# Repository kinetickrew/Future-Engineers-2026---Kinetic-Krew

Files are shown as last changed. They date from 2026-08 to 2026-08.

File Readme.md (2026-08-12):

# WRO 2026 Future Engineers — Engineering Documentation

## Table of Contents

1. [Competition Context](#competition-context)
2. [On The Name](#On-The-Name)
3. [System Architecture Overview](#system-architecture-overview)
4. [Chassis and Construction Materials](#chassis-and-construction-materials)
5. [Bill of Materials](#Bill-of-Materials)
6. [Robot at a Glance](#robot-at-a-glance)
7. [Layered Chassis Design](#layered-chassis-design)
8. [Design Evolution](Design-Evolution)
9. [Steering Mechanism — Ackermann Steering](#steering-mechanism--ackermann-steering)
10. [Servo Motor Integration with the Ackermann Steering Mechanism](#servo-motor-integration-with-the-ackermann-steering-mechanism)
11. [Differential Gear System](#differential-gear-system)
12. [Relation with the DC Motor](#relation-with-the-dc-motor)
13. [Power System](Power-System)
14. [Motor Torque & Top Speed: Theoretical vs. Measured](#motor-torque--top-speed-theoretical-vs-measured)
15. [Software Architecture](Software-Architecture)
16. [Getting Started](Getting-Started)
17. [Engineering Decisions](#Engineering-Decisions)
18. [Computer Vision Pipeline & Mathematical Foundations](#computer-vision-pipeline--mathematical-foundations)
19. [ESP32 Maze-Navigating & Self-Stabilizing Subsystem](#esp32-maze-navigating--self-stabilizing-subsystem)
20. [PID Control — Background Theory](#pid-control--background-theory)
21. [Glossary](#glossary)

---

## Competition Context

WRO Future Engineers is the World Robot Olympiad's self-driving car category, aimed at students roughly 14–19 years old. Teams design, build, and program a model vehicle that must complete laps of a track fully autonomously, without any remote control, using whatever combination of controllers, motors, and sensors they choose as long as it fits the general rules. Students design a model car, equip it with electromechanical components, and program it to autonomously drive on a track and avoid obstacles. The category is explicitly built to mirror real self-driving car research, so teams are encouraged to reason about the same engineering trade-offs that full-size autonomous vehicle manufacturers face: steering geometry, sensor fusion, control-loop tuning, and mechanical reliability under repeated real-world testing.

The 2026 season runs two distinct challenge formats, each scored as a timed, single-car run rather than a head-to-head race:

- **Open Challenge** — the vehicle must complete three laps on the track with random placements of the inside track walls, testing pure lane-keeping and heading control without obstacles.
- **Obstacle Challenge** — the vehicle must complete three laps on the track with randomly placed green and red traffic signs, where the signs indicate which side of the lane the vehicle must follow: a red pillar means "keep to the right of the lane" and a green pillar means "keep to the left." Later rounds of the obstacle challenge also require the vehicle to identify a parking space and execute a parallel-parking maneuver to finish the run.

Both challenges are run as **Time Attack** events — only one car is on the track at a time, and each car tries to record the best time driving several fully autonomous laps. Teams are also evaluated on an **Engineering Journal**, which documents design decisions, prototyping iterations, and justifications for chosen components — this repository and its documentation serve that purpose for our team.

Because obstacle placement, wall layout, and (in later rounds) parking-bay location are randomized before each run, the robot cannot rely on a memorized path. This is the core reason our design combines deterministic mechanical geometry (Ackermann steering, a differential drivetrain) with adaptive, sensor-driven control loops (computer vision pillar detection, LiDAR wall-following, IMU heading correction) rather than depending on either alone.

---

## On The Name

We named our robot **Steve**. Not an acronym, not a backronym, not "Self-Tracking Vehicle with Enhanced-something" — just Steve. Somewhere in our design process, between tuning a discrete Kalman filter, wiring a 3-way LiDAR array, and debugging heading drift across a 0°↔360° boundary, we realized the robot deserved a name with the same energy as the engineering was clearly lacking. We wanted something the judges would remember. Turns out nothing is more memorable than a $400 autonomous vehicle named after someone's uncle. So Steve it is — and frankly, given how confidently he snaps to cardinal headings and swerves around pillars, he's earned it

---

## System Architecture Overview

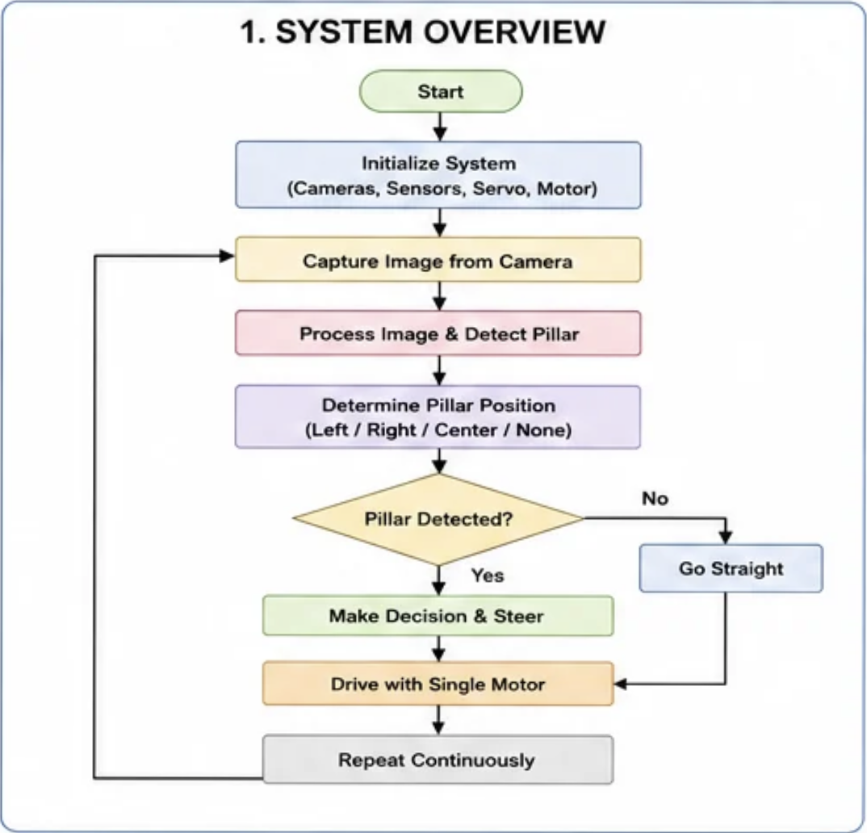
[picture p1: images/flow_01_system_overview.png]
<p align="center"> <br> <em>High-level operating loop: from sensor initialization through continuous drive decisions, tying together the three architecture layers described above.</em> </p>

Our platform is best understood as three cooperating layers:

1. **Mechanical layer** — a LEGO EV3 Technic chassis with Ackermann front steering, a rear differential, and custom 3D-printed sensor/actuator mounts. This layer guarantees that whatever heading and speed commands the software issues get translated into smooth, low-slip motion.
2. **Perception layer** — a camera-based YOLO object detector (ONNX Runtime, CPU inference on the Raspberry Pi 5) for identifying red/green pillars, paired with a 3-way TF-Luna LiDAR array and a BNO055 absolute orientation sensor for wall-following, turn-triggering, and heading stabilization.
3. **Control layer** — a temporal-vote confirmation scheme for stable detections, a one-time waypoint/arc geometry calculation for routing around confirmed obstacles, a PID heading-hold controller for straight-line driving, and a UART/serial link that turns high-level decisions (`CLEAR`, `STOP`, `WAYPOINT`, `REVERSE`) into low-level servo and motor commands.

The sections below document each layer in the depth captured in our design notes, plus supporting engineering background.

---

## Chassis and Construction Materials

Our WRO 2026 Future Engineers robot is built using a combination of LEGO EV3 Technic components and custom-designed 3D-printed parts. This hybrid approach allows us to take advantage of the strength and precision of EV3 while incorporating custom mounts for electronic components that cannot be accommodated using standard LEGO parts.

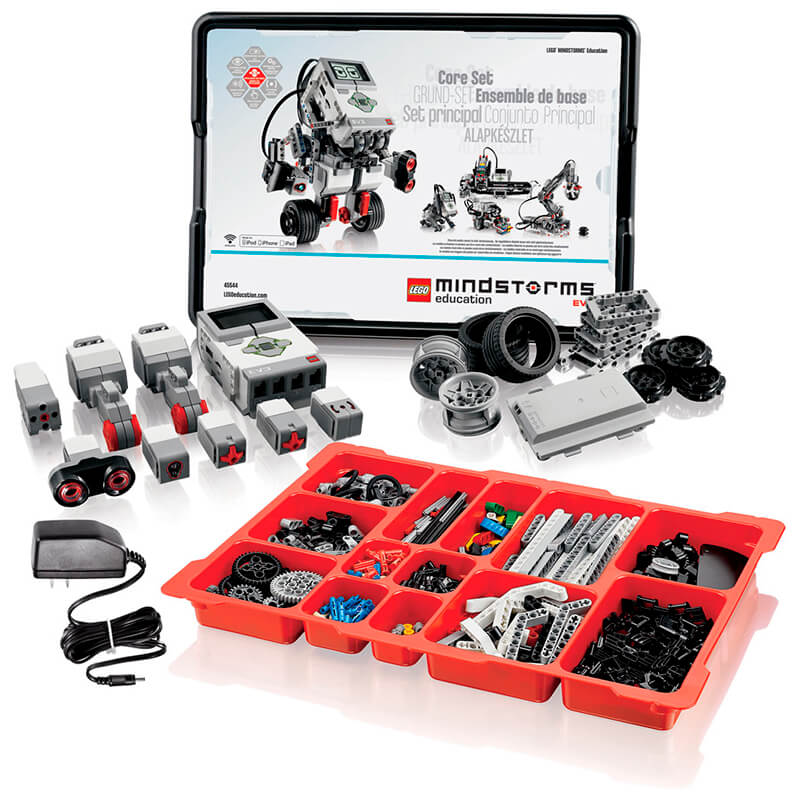
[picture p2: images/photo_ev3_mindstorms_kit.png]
<p align="center"> <br> <em>The LEGO Mindstorms EV3 Core Set — the base kit our Technic chassis, beams, and gearing are built from.</em> </p>

The main chassis is constructed from LEGO EV3 Technic beams, frames, gears, and connectors. These components are specifically designed for mechanical applications and provide excellent structural rigidity while remaining lightweight. Their standardized dimensions ensure accurate alignment of axles, gears, and bearings, resulting in smooth power transmission and reliable mechanical performance. Additionally, the modular nature of the EV3 system allows the robot to be assembled, modified, and repaired quickly, which proved especially valuable during testing and iterative design improvements.

Compared to a fully 3D-printed chassis, the EV3 structure offers several advantages. Although 3D printing provides greater design freedom, large printed frames are generally more susceptible to layer separation, slight dimensional inaccuracies, and deformation under continuous mechanical loads. These issues can affect gear alignment and steering accuracy over time. In contrast, EV3 components are manufactured with high precision and consistent tolerances, ensuring stronger connections, improved durability, and smoother operation of moving mechanical parts. Their proven reliability makes them particularly suitable for a competition robot that must perform consistently over multiple runs.

While EV3 forms the foundation of our robot, several custom 3D-printed components were designed to integrate modern sensors and actuators that cannot be mounted efficiently using LEGO elements alone. These custom parts include:

- **LiDAR mount** — positions the sensor securely and provides an unobstructed 360° field of view for environmental scanning.
- **Camera mount** — placed at an optimized height and angle to maximize the accuracy of lane detection, obstacle recognition, and computer vision algorithms.
- **DC motor mount** — provides a rigid connection between the motor and drivetrain to minimize unwanted movement and improve power transmission efficiency.
- **Servo motor mount** — plays a critical role in the Ackermann steering system by maintaining precise alignment between the servo horn and steering linkage. A rigid and accurately positioned mount ensures consistent steering angles and reduces mechanical play, directly improving the robot's steering precision.

By combining the mechanical reliability of the LEGO EV3 platform with the flexibility of custom 3D-printed components, our robot benefits from both standardized engineering and application-specific customization. This hybrid design improves structural strength, simplifies maintenance, and enables seamless integration of advanced sensors and actuators, resulting in a robust and competition-ready autonomous vehicle.

---

## Bill of Materials

### Mechanical / LEGO Technic Components

Generated from our Stud.io CAD model export — 151 total pieces, ~214g.

| Part # | Part Name | Color | Qty | Weight (g, ea) | Source  | Cost (per pc) | Cost (total) |
| --- | --- | ---: | ---: | ---: | --- | ---: | ---: |
| 62821b | Technic Gear Differential 28T Bevel, Closed Center | Dark Bluish Gray | 1 | — | EV3 Kit | $2.50 | $2.50 |
| 6589 | Technic Gear 12 Tooth Bevel | Tan | 3 | 0.29 | EV3 Kit | $0.35 | $1.05 |
| 41897 | Tire 56 x 28 ZR Street | Black | 2 | 13.98 | EV3 Kit | $0.70 | $1.40 |
| 89201 | Tire 24 x 14 Shallow Tread | Black | 2 | 2.55 | EV3 Kit | $0.30 | $0.60 |
| 56908 | Rim 43.2mm D. x 26mm Technic Racing Small | Gray | 2 | 9.0 | EV3 Kit | $0.60 | $1.20 |
| 55982 | Rim 18mm D. x 14mm w/ Axle Hole | Gray | 2 | 1.75 | EV3 Kit | $0.25 | $0.50 |
| 64179 | Technic Liftarm Frame Thick 5x7 Open Center | Light Bluish Gray | 3 | 5.3 | EV3 Kit | $0.60 | $1.80 |
| 64782 | Technic Panel Plate 5 x 11 x 1 | Orange | 4 | 8.8 | EV3 Kit | $0.80 | $3.20 |
| 41239 | Technic Liftarm Thick 1x13 | Light Bluish Gray | 7 | 3.3 | EV3 Kit | $0.40 | $2.80 |
| 32525 | Technic Liftarm Thick 1x11 | Light Bluish Gray | 6 | 2.8 | EV3 Kit | $0.35 | $2.10 |
| 32524 | Technic Liftarm Thick 1x7 | Light Bluish Gray | 6 | 1.74 | EV3 Kit | $0.25 | $1.50 |
| 40490 | Technic Liftarm Thick 1x9 | Light Bluish Gray | 4 | 2.59 | EV3 Kit | $0.30 | $1.20 |
| 60484 | Technic Liftarm Modified T-Shape Thick 3x3 | Black | 5 | 1.19 | EV3 Kit | $0.25 | $1.25 |
| 32526 | Technic Liftarm Modified Bent L-Shape 3x5 | White / Lt Bluish Gray | 2 + 4 | 1.77 | EV3 Kit | $0.30 | $1.80 |
| 32140 | Technic Liftarm Modified Bent L-Shape 2x4 | Light Bluish Gray | 2 | 1.43 | EV3 Kit | $0.25 | $0.50 |
| 32316 | Technic Liftarm Thick 1x5 | Light Bluish Gray | 2 | 1.21 | EV3 Kit | $0.20 | $0.40 |
| 43857 | Technic Liftarm Thick 1x2 | Light Bluish Gray | 4 | 0.4 | EV3 Kit | $0.15 | $0.60 |
| 48989 | Technic Pin Connector Perpendicular 3L w/ 4 Pins | Light Bluish Gray | 2 | 1.22 | EV3 Kit | $0.30 | $0.60 |
| 44809 | Technic Pin Connector Perpendicular 2x2 Bent | Red | 2 | 0.5 | EV3 Kit | $0.25 | $0.50 |
| 6558 | Technic Pin 3L with Friction Ridges | Blue | 19 | 0.31 | EV3 Kit | $0.15 | $2.85 |
| 2780 | Technic Pin with Short Friction Ridges | Black | 55 | 0.16 | EV3 Kit | $0.10 | $5.50 |
| 15100 | Technic Pin with Friction Ridges and Pin Hole | Black | 2 | 0.4 | EV3 Kit | $0.15 | $0.30 |
| 3713 | Technic Bush | Light Bluish Gray | 4 | 0.14 | EV3 Kit | $0.10 | $0.40 |
| 4265c | Technic Bush 1/2 Smooth | Yellow | 2 | 0.1 | EV3 Kit | $0.10 | $0.20 |
| 3737 | Technic Axle 10L | Black | 2 | 1.49 | EV3 Kit | $0.30 | $0.60 |
| 3749 | Technic Axle 1L with Pin, no friction ridges | Tan | 2 | 0.22 | EV3 Kit | $0.15 | $0.30 |
| **Total** | | | **151 pcs** | **~214 g** | | | **$31.75** |

### Electronics / Control

|Component|Model / Part #|Qty|Purpose|Source|Cost (approx.)|
|---|---|--:|---|---|--:|
|Microcontroller|ESP32-WROOM-32 DevKit (dual-core, 240 MHz)|1|Low-level control, FSM, PID steering|Amazon|$9|
|Vision compute|Raspberry Pi 5, 8GB|1|Camera capture + CV pipeline|raspberrypi.com|$85|
|IMU|Adafruit BNO055 Absolute Orientation Sensor (Product ID 2472)|1|Heading hold, cardinal snapping|adafruit.com|$34.95|
|LiDAR|Benewake TF-Luna I2C/UART ToF LiDAR|3|Left/Center/Right wall-following|DFRobot|$90 for all 3|
|I2C Multiplexer|Adafruit TCA9548A (Product ID 2717)|1|Channel-isolate identical-address LiDARs + IMU|adafruit.com|$6.95|
|Steering actuator|TowerPro SG90 micro servo (9g, ~1.8 kg·cm torque)|1|Ackermann steering actuation|Amazon|$4|
|Drive motor|GA12-N20, 12V, 600 RPM metal gear motor|1|Propulsion via differential|Amazon|$6|
|Motor driver|PWM DC motor driver(tb6612fng)|1|Speed control for N20 motor|Amazon|$5|
|Camera|Lenovo 300 FHD Webcam (USB, 1080p/2.1MP CMOS, 95° lens, 4x digital zoom, 360° rotation, dual mics)|1|Pillar color/shape detection|Amazon|$25|
|Battery|11.1V, 3S, 60C, LiPo, 2200 mAh|1|Power source|Amazon|$15|

### 3D-Printed Custom Parts

|Part|Purpose|Qty|Print material/cost basis|Cost|
|---|---|--:|---|--:|
|LiDAR mount|Secure 360° FOV positioning|1|In-house 3D print|$1|
|Camera mount|Optimized height/angle for CV|1|In-house 3D print|$1|
|DC motor mount|Rigid drivetrain connection|1|In-house 3D print|$1|
|Servo mount|Precise Ackermann linkage alignment|1|In-house 3D print|$1|
|**3D-printed subtotal**||**4**||**$4**|

_LEGO parts list generated from our Stud.io CAD model export (see `CAD-Files/`)._

---

## Robot at a Glance

|Spec|Value|
|---|---|
|Total weight|870 g|
|Length (frontmost to rearmost)|175 mm|
|Height (with camera)|190 mm|
|Height (without camera)|170 mm|
|Wheelbase (front axle to rear axle)|90 mm|
|Front track width (inner edge / outer edge)|91.5 mm / 117 mm|
|Rear track width (inner edge / outer edge)|130.22 mm / 165 mm|
|Ground clearance (front)|3 mm|
|Ground clearance (rear)|15 mm|

**Note on ground clearance:** Steve's ground clearance is meaningfully lower at the front (3mm) than the rear (15mm). This asymmetry is a natural consequence of the layered chassis design (see "Layered Chassis Design"), where heavier components (battery, Raspberry Pi) sit low and toward the rear/center to lower the robot's center of gravity — the front, carrying only the lighter steering assembly, sits closer to the ground. The very low front clearance (3mm) is worth flagging as a practical consideration: it leaves little margin for uneven track surfaces or debris under the front steering assembly before contact risk becomes a factor.

---

## Layered Chassis Design

A key design objective for our robot was to achieve a compact, well-balanced, and mechanically robust structure. To accomplish this, we adopted a layered chassis design using LEGO EV3 Technic beams and LEGO Technic panel plates. This approach allowed us to separate the robot into multiple functional levels while maintaining a rigid and modular frame.

The upper layer houses the electronic circuit and wiring, making them easily accessible for maintenance and reducing cable interference with the drivetrain and steering components. The lower layer accommodates heavier components, including the Raspberry Pi and the battery pack. Positioning these components closer to the ground lowers the robot's center of gravity, improving overall stability.

A lower center of gravity significantly enhances the robot's performance during high-speed maneuvers. As the robot enters a corner, weight transfer is reduced, minimizing body roll and helping all four wheels maintain better contact with the ground. This increases the effective downward force acting on the wheels, resulting in improved tire grip and allowing the robot to take corners at higher speeds while maintaining accurate control. The balanced weight distribution also contributes to smoother steering response and reduces the likelihood of tipping or instability during rapid direction changes.

The layered construction was made possible using LEGO Technic panel plates, which serve as sturdy platforms between the chassis levels. These panels are securely supported by various LEGO EV3 Technic beams and connectors, creating a lightweight yet rigid structure capable of withstanding repeated testing and competition conditions.

By organizing the robot into dedicated layers, we achieved a clean mechanical layout, simplified maintenance, improved protection for electronic components, and enhanced driving performance through a lower center of gravity and more stable weight distribution.

---

## Design Evolution

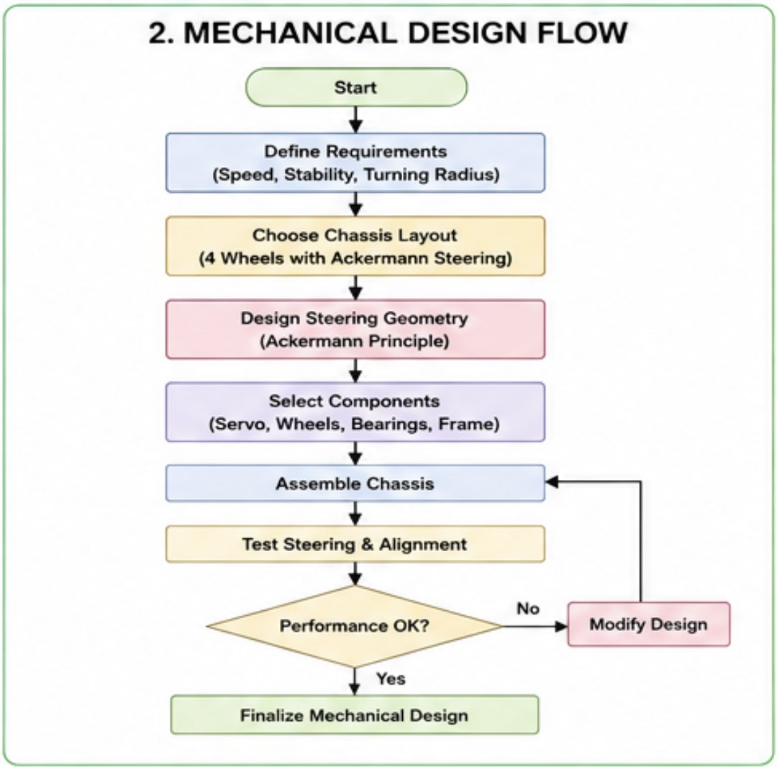
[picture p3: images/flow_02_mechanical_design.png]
<p align="center"> <br> <em>General mechanical design process followed for Steve's chassis and steering — each entry below documents a specific problem encountered and fix made within this process.</em> </p>

### Steering Linkage: Play at the Joints

**Problem:** The steering linkage had play at the joints, leading to inconsistent steering angles between identical commanded positions.

**Modification:** We redesigned the servo linkage.

**Result:** We verified the fix by repeatedly commanding the servo between 0° and 90° (0 → 90 → 0 → 90...) and measuring the actual wheel angle at each step by hand, noting any inconsistencies between repeated commands to the same angle.

---

### Steering Mount: 3D-Printed Part Redesign

**Problem:** An earlier 3D-printed steering mount part was weakly secured to the chassis, using pivot-style attachment points that didn't hold firmly under repeated steering loads.

**Modification:** We reprinted the part at a denser infill for greater structural strength, and switched the attachment method from pivots to screws for a rigid, fixed connection to the chassis.

**Result:** The part now holds securely under repeated steering loads, with no further loosening at the mounting point.

---

### Drive Motor: N20 Mount Redesign

**Problem:** Our first mount for the N20 drive motor was not structurally sound and broke off from the chassis under normal operation.

**Modification:** We redesigned the motor mount for a more rigid, secure connection to the chassis.

**Result:** No further mount failures after the redesign.

---

### Drive Motor: Upgrading from 200 RPM to 600 RPM

**Problem:** Our original N20 motor was rated at 200 RPM. At full drive signal (255 PWM), this motor only completed our test lap distance in 12 seconds — too slow for competitive lap times.

**Modification:** We switched to a GA12-N20, 12V, 600 RPM motor, giving substantially higher output speed at the same 255 PWM drive signal.

**Result:** With the 600 RPM motor, our bot completed one round, in around 9.8 seconds, significantly faster, gaining around 3.5 seconds across 3 laps.

---

### Computer Vision: HSV Threshold Recalibration Tooling _(historical — pipeline since replaced)_

**Problem:** Our color-detection pipeline relies on fixed HSV threshold bounds to isolate red and green pillars. Thresholds tuned under one lighting condition do not necessarily hold under a different one, since ambient lighting shifts the same pillar's Hue/Saturation/Value readings.

**Modification:** We built a dedicated tool to retune HSV threshold values directly, letting us recalibrate quickly instead of hand-editing constants in code for every lighting condition. The tool is available in this repository at [`src/vision/scripts/hsvcali.py`]

**Result:** When moving from Orange to White lighting, earlier we had to take around 20 photos of the pillars, and get the mean rgb values, which took around 30 minutes, but now with this tool, using OpenCV, we can do it much quicker, in under 5 minutes.

**Note:** This HSV-threshold pipeline and its recalibration tool have since been retired in favor of a trained YOLO object detector (see "Computer Vision Pipeline & Mathematical Foundations"). This entry is kept as a record of the design's history.

---

### Sensors: LiDAR I2C Address Conflict

**Problem:** All three TF-Luna LiDAR units share the same default I2C address (`0x10`). Wiring them directly onto the ESP32's I2C bus caused an address conflict, since the microcontroller couldn't distinguish which sensor it was communicating with.

**Modification:** We added a TCA9548A I2C multiplexer between the ESP32 and the three LiDAR units, assigning each sensor to its own multiplexer channel (Left: Ch 0, Center: Ch 1, Right: Ch 2).

**Result:** Fully resolved the address collision — all three LiDAR units now operate independently and reliably on a single I2C bus.

---

## Steering Mechanism — Ackermann Steering

### Overview

Our WRO 2026 Future Engineers robot uses an Ackermann steering mechanism, which closely replicates the steering geometry used in real passenger cars. This design allows the robot to turn smoothly while maintaining stability and reducing tire friction. Since the WRO Future Engineers challenge focuses on autonomous self-driving vehicles, Ackermann steering provides realistic vehicle dynamics and improves navigation accuracy.

### How Ackermann Steering Works

When a vehicle turns, the inner front wheel follows a smaller turning radius than the outer front wheel. Therefore, both wheels cannot be steered by the same angle.

The Ackermann steering mechanism solves this by ensuring:

- The inner wheel turns at a larger angle.
- The outer wheel turns at a smaller angle.
- Both wheels point toward the same instantaneous center of rotation, allowing the vehicle to roll through the corner without unnecessary wheel slip.

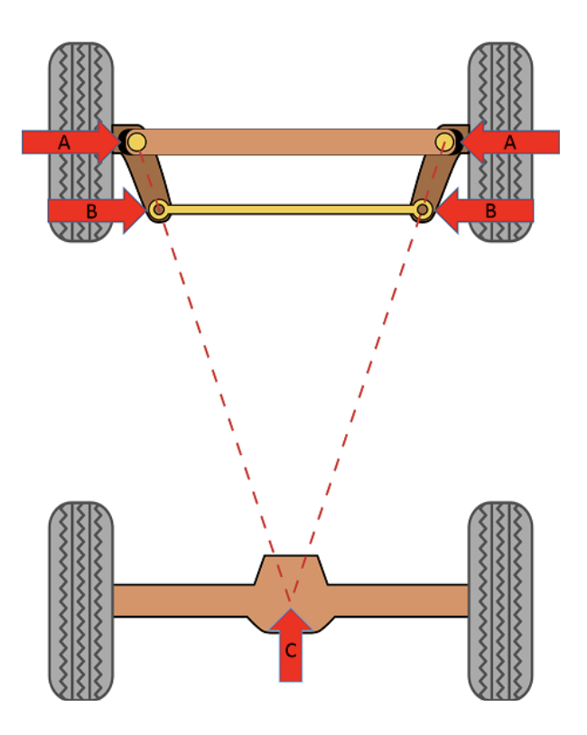
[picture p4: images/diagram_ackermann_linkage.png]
<p align="center"> <br> <em>Ackermann steering linkage: the tie-rod geometry (A, B) is angled so both front wheels' steering axes converge on a single point (C) on the extended rear axle line.</em> </p>

In our robot:

- A servo motor controls the steering.
- The servo moves a steering linkage connected to both front wheels.
- Carefully designed steering arms create different steering angles for the left and right wheels, following Ackermann geometry.
- The rear wheels provide propulsion through the drive motor, while the front wheels are responsible only for steering.

### The Ackermann Equation

The relationship between the inner steering angle δᵢ and the correct outer steering angle δₒ is a function of two chassis dimensions: the **wheelbase** L (distance between front and rear axles) and the **track width** W (distance between the left and right kingpins/steering pivots). The standard low-speed, pure-rolling condition is expressed as:

```
cot(δₒ) = cot(δᵢ) + W / L
```

This means that for a given inner wheel angle, the correct outer wheel angle is always slightly smaller — using equal angles (parallel steering) instead forces the outer tire to scrub laterally, wasting energy and wearing the tire. On Steve's actual chassis — a 90mm wheelbase (L) and 104.25mm front track width (W, averaged from center-to-center inner/outer wheel measurements) — commanding the inner wheel to Steve's actual maximum steering angle of 14.5° (the firmware commands the servo to its `DIFF = 25°` limit, but the steering linkage's mechanical leverage ratio means the front wheels themselves only deviate 14.5° at that command — see "Servo Motor Integration" for the linkage) requires the outer wheel to sit at approximately 12.0°, not 14.5°, for true Ackermann geometry to hold.

Geometrically, this condition is equivalent to requiring that a line drawn through each kingpin axis and the outer end of its steering arm, when extended backward, intersects at a single point on the centerline of the rear axle. When that construction holds, both front tires roll about the same turn center without scrubbing at low speed. Real linkages only approximate this condition well within a limited range of steering angles — at very small steering angles (gentle bends), the difference between the inner and outer angle is small enough to be almost negligible, so the benefit of true Ackermann geometry becomes most noticeable in sharper turns, which is exactly the regime our robot operates in when swerving around pillars or taking tight corners on the WRO track.

It is also worth noting that full-size vehicles often intentionally use **less** than 100% Ackermann geometry at speed, because tire slip angles at higher speed reduce the need for the same geometric correction that matters at low, parking-lot speeds. Since our robot operates at comparatively low speeds and small scale, we tuned our steering arms toward closer-to-ideal Ackermann geometry, prioritizing low-slip precision over high-speed compliance.

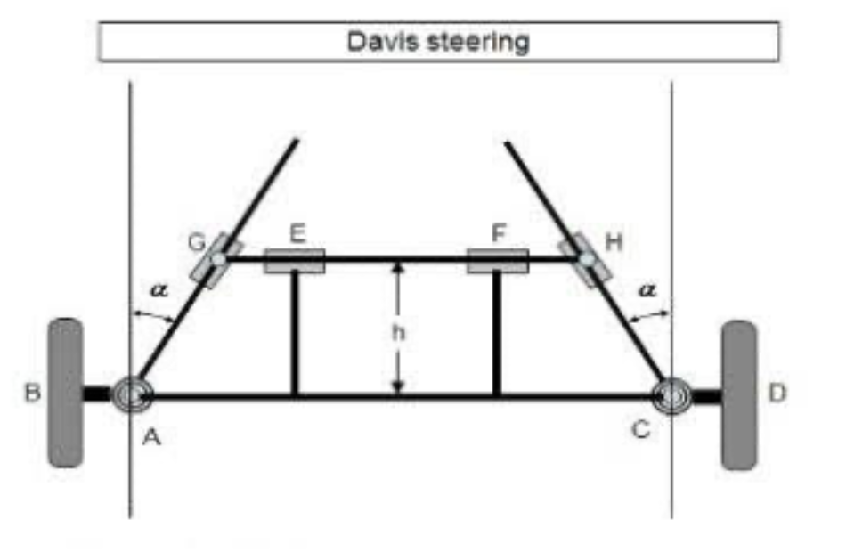
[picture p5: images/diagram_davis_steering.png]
<p align="center"> <br> <em>Davis steering — the sliding-linkage alternative to Ackermann's four-bar geometry. We evaluated this layout but chose the pivoted trapezoidal (Ackermann) linkage above for lower friction and simpler mounting on the EV3 frame.</em> </p>

### Turning Radius Calculation

Using the bicycle-model approximation, with wheelbase L = 90mm and Steve's actual maximum front wheel steering angle δ = 14.5° (measured at the wheel — not the 25° commanded at the servo; see note below):

```
R = L / tan(δ)
  = 90mm / tan(14.5°)
  = 90mm / 0.2586
  ≈ 348.0 mm
```

This gives Steve's approximate minimum turning radius — roughly 348mm (about 34.8 cm) — the tightest circle the robot can complete at maximum steering lock, measured from the center of the rear axle to the instantaneous center of rotation.

**Note on servo angle vs. wheel angle:** The firmware's `DIFF = 25°` (see Bluetooth Serial Calibration Console) is the maximum angle commanded at the _servo horn_, not the actual front wheel angle. Steve's steering linkage has a mechanical leverage ratio that reduces this to a measured 14.5° at the wheels themselves — using the uncorrected 25° figure in this calculation would have overstated Steve's actual turning ability by a significant margin (a naive calculation using 25° would suggest a ~193mm radius, nearly half the real value). This is a good example of why measuring the real mechanical output, rather than trusting the commanded input value, matters for an accurate spec.

**⚠️ Simplification noted:** This is a single-track (bicycle model) approximation, treating the front axle as one steered wheel at the average Ackermann angle rather than separately modeling the inner and outer wheels' slightly different angles (12.0° vs. 14.5°, per the Ackermann Equation above). A more precise geometric calculation would use the inner wheel's actual turning circle directly, which would give a very slightly tighter radius than this approximation.

### Advantages of Ackermann Steering

- Reduced tire slipping during turns.
- Smaller turning radius, allowing the robot to navigate tight corners.
- Improved path accuracy, especially when following lanes and avoiding obstacles.
- Better vehicle stability at higher speeds.
- Lower mechanical wear because the wheels roll naturally instead of skidding.
- Realistic car-like behavior, making autonomous control algorithms easier to tune and more consistent with real vehicles.

### Why We Chose Ackermann Steering

For the WRO Future Engineers competition, precise steering is essential for lane following, obstacle avoidance, and consistent lap times. Compared to differential drive robots, Ackermann steering produces smoother trajectories, more predictable turning behavior, and improved control at speed. This makes it well suited for autonomous driving challenges where accuracy and repeatability are critical.

### Simplified Steering Diagram

```
        Front

      /         \
 Inner Wheel   Outer Wheel
 (larger angle) (smaller angle)

        \       /
         \     /
   Instantaneous
 Rotation Center

        Rear Drive Wheels
```

This geometry ensures that all four wheels follow circular paths with a common center during a turn, minimizing slip and maximizing steering efficiency.

---

## Servo Motor Integration with the Ackermann Steering Mechanism

The Ackermann steering mechanism in our WRO 2026 Future Engineers robot is actuated by a high-torque servo motor, which provides precise control over the steering angle of the front wheels. Unlike a standard DC motor, a servo motor can rotate to a specific position based on the control signal it receives, making it ideal for accurate steering.

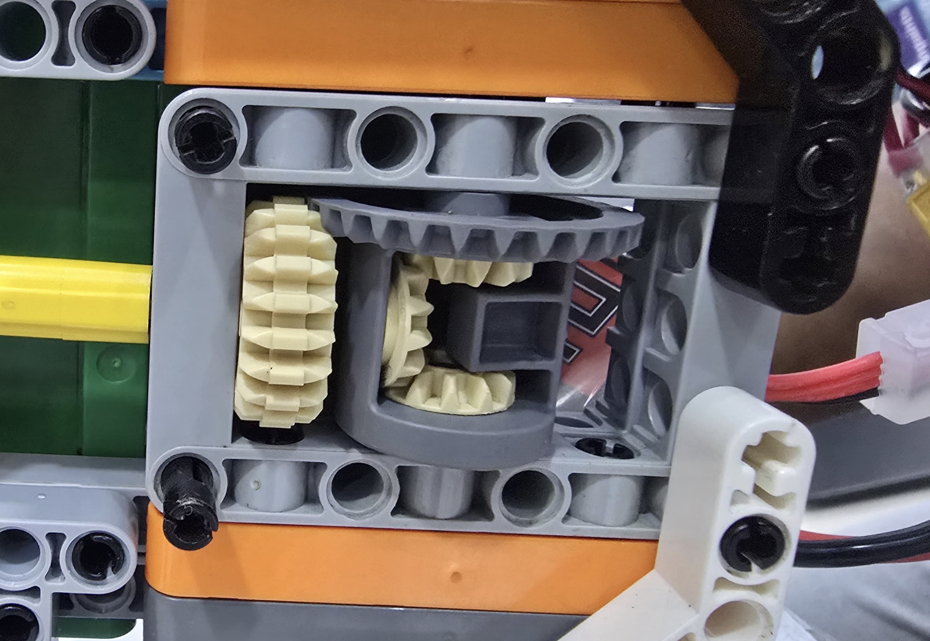
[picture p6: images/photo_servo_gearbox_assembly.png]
<p align="center"> <br> <em>The servo gearbox mounted to the chassis, meshing into the steering linkage gear train.</em> </p>

### How the Servo Controls Steering

The servo motor is mounted near the front axle and is connected to the steering linkage through a servo horn and a steering rod. When the autonomous control algorithm determines that the robot must turn, it sends a steering command to the servo. The servo rotates to the required angle, pulling or pushing the steering linkage.

As the linkage moves:

- The left and right steering arms rotate together.
- Due to the Ackermann steering geometry, the inner wheel automatically turns more than the outer wheel.
- The front wheels align with the correct turning radius, allowing the robot to corner smoothly with minimal wheel slip.

Because the servo can move to precise angular positions, the robot can make small steering corrections while driving, improving lane following and obstacle avoidance.

### Advantages of Using a Servo Motor

- High positioning accuracy enables precise steering control.
- Fast response time allows quick adjustments during autonomous navigation.
- Repeatable movement ensures consistent steering performance across multiple runs.
- Compact and lightweight, making it suitable for WRO vehicle designs.
- Easy integration with common robot controllers such as Arduino, Raspberry Pi, and ESP32 using PWM (Pulse Width Modulation).

By combining a servo motor with the Ackermann steering mechanism, our robot achieves smooth, accurate, and reliable steering that closely resembles the behavior of a real automobile. This combination improves navigation performance, increases stability during turns, and helps the robot maintain accurate trajectories throughout the WRO Future Engineers challenge.

---

## Differential Gear System

### Overview

Our WRO 2026 Future Engineers robot uses the LEGO EV3 Differential Gear as part of its drivetrain. The differential is installed between the rear drive wheels and is responsible for distributing power while allowing each wheel to rotate at different speeds during a turn. This mechanism is widely used in real automobiles because it improves handling, reduces mechanical stress, and enables smoother cornering.

### How the Differential Gear Works

A differential consists of a set of bevel gears housed within a differential casing. Power from the drive motor is transmitted to the differential, which then distributes torque to both rear wheels.

When the robot travels in a straight line:

- Both rear wheels rotate at the same speed.
- The internal gears do not rotate relative to one another.
- Power is evenly distributed to both wheels.

When the robot enters a turn:

- The outer wheel must travel a greater distance than the inner wheel.
- The differential allows the outer wheel to rotate faster while the inner wheel rotates more slowly.
- Torque continues to be transmitted to both wheels, allowing the robot to maintain traction throughout the turn.

This ability to accommodate different wheel speeds is essential for smooth and efficient vehicle movement.

### Integration with the Ackermann Steering System

The differential gear works together with the Ackermann steering mechanism to produce realistic vehicle dynamics.

As the servo motor steers the front wheels according to Ackermann geometry, the rear differential automatically compensates for the difference in wheel travel. Since the outer rear wheel follows a larger turning radius, it rotates faster than the inner rear wheel. The differential enables this speed difference without causing wheel slip or excessive mechanical stress.

Together, these two systems allow the robot to corner smoothly while maintaining stability and accurate path tracking.

### Advantages of Using the EV3 Differential

- Allows the rear wheels to rotate at different speeds during turns.
- Reduces tire scrubbing and wheel slip.
- Improves stability and handling while cornering.
- Minimizes stress on the drivetrain and gears.
- Increases the efficiency of power transmission.
- Produces realistic car-like driving behavior, similar to full-sized automobiles.

### Why We Chose the EV3 Differential

The LEGO EV3 Differential Gear is compact, reliable, and easy to integrate with Technic components. It provides a proven mechanical solution that requires no additional programming to compensate for wheel speed differences. By combining the EV3 differential with our Ackermann steering mechanism, the robot achieves smoother turns, better traction, and more predictable autonomous navigation throughout the WRO Future Engineers challenge.

### Simplified Differential Diagram

```
            Drive Motor
                 │
                 ▼
        ┌─────────────────┐
        │  Differential   │
        └─────────────────┘
          │             │
          ▼             ▼
     Left Rear     Right Rear
       Wheel          Wheel

Straight:  Same wheel speed
Turning:   Outer wheel rotates faster than inner wheel
```

---

## Relation with the DC Motor

The differential gear is driven by a DC motor, which provides the power required to propel the robot. The motor transfers rotational motion to the differential, which then distributes torque to both rear wheels. During turns, the differential automatically allows each wheel to rotate at a different speed while the DC motor continues to provide a constant power input, ensuring smooth and efficient movement.

---

## Power System

Steve is powered by a single 11.1V 3S LiPo battery (2200mAh, 60C discharge rating — see "Power Source: Li-ion vs. LiPo Battery" in Engineering Decisions), which is split across two separate 5V buck converter modules.

### Power Budget

|Component|Qty|Typical Current (each)|Peak Current (each)|Typical Total|Peak Total|
|---|--:|--:|--:|--:|--:|
|Raspberry Pi 5 (8GB)|1|~0.6–1A|~3A¹|~0.8A|~3A|
|ESP32-WROOM-32|1|~130mA|~380mA|~130mA|~380mA|
|Steering servo (SG90)|1|~5mA (idle) / ~200mA (moving)|~500–700mA (stall)|~200mA|~700mA|
|Drive motor (GA12-N20, 12V/600RPM)|1|~0.06A|0.75A|—|—|
|TF-Luna LiDAR|3|~70mA|~150mA|~210mA|~450mA|
|BNO055 IMU|1|~12mA²|~12mA²|~12mA|~12mA|
|**Total**||||**~1.41A**|**~5.25A**|

¹ Pi 5 peak current depends heavily on connected USB load; ~3A is a conservative estimate since Steve doesn't drive heavy USB peripherals off the Pi. ² BNO055 current draw is a commonly cited approximate datasheet figure, not independently re-verified — treat as indicative.

### Voltage Regulation Path

```
                        11.1V 3S LiPo (2200mAh, 60C, XT30/XT60 connector)
                                   │
                 ┌─────────────────┴─────────────────┐
                 ▼                                     ▼
        Buck Converter #1 (5V)                Buck Converter #2 (5V)
                 │                                     │
                 ▼                                     ▼
        Raspberry Pi 5                        ESP32 VIN, motor driver
        (via USB-C power input)               logic rail, servo power
                                                        │
                                              ┌─────────┴──────────┐
                                              ▼                    ▼
                                     ESP32 onboard 3.3V    Motor driver → 
                                     regulator → BNO055,   raw battery voltage
                                     TCA9548A I2C bus      → drive motor
```

Steve runs two independent 5V buck converters rather than a single shared regulator, and this split is deliberate rather than incidental: the **Round 1 (Open Challenge)** configuration does not use the Raspberry Pi 5 at all, since Round 1 doesn't require the vision pipeline's obstacle detection — only wall-following and heading-hold via the ESP32, LiDAR, and BNO055. Keeping the Pi 5 on its own dedicated converter means the Pi can be left unpowered entirely for Round 1 runs without needing to rewire or partially disable a shared power rail, and it means Pi-side current draw (which is both larger and more variable than the ESP32 side) never has the chance to sag the voltage feeding the ESP32's real-time control loop, even in Round 2 configurations where both processors are active.

Downstream of the ESP32-side 5V rail:

- The **ESP32's onboard 3.3V regulator** supplies the BNO055 IMU and TCA9548A I2C multiplexer.
- The **motor driver board** receives both the regulated 5V logic supply and a separate raw battery-voltage connection, which it switches to the drive motor — standard topology for motor drivers, since the motor needs full battery voltage/current while only the driver's control logic needs 5V.
- The **servo** draws its power from the 5V rail directly.

### Safety Notes

**Fusing:** Steve currently has **no fusing** anywhere in the power path — not between the battery and either buck converter, and not between the battery and the motor driver. This is a known gap: an unfused short circuit (e.g. a pinched or frayed wire, a real risk given how often the robot is handled and transported between testing sessions) has no protection beyond whatever current-limiting the LiPo's own protection circuitry or the buck converters provide. We have not yet added fusing and are documenting this as a current limitation rather than a resolved item.

**Reverse-polarity protection:** The battery connects via an XT30/XT60 connector, which is keyed and cannot physically be inserted in reverse — this gives us inherent reverse-polarity protection at the battery connection itself without needing a separate protection diode. This protection does not extend past the connector, however — the buck converters' screw-terminal inputs could still be wired backwards during assembly or maintenance, so care during wiring remains necessary there.

**Stall-current handling:** The drive motor's stall current is 0.75A, the largest single current draw in the system, occurring whenever the wheels are physically blocked while the motor is still commanded to drive. The motor driver sits between the battery and motor specifically to handle this. Since it's a generic TB6612FNG breakout board, the chip itself is typically rated for up to 1.2A continuous / 3.2A peak per channel — comfortably above the motor's 0.75A stall current, giving the driver clear headroom. The LiPo's 60C discharge rating (≈132A theoretical max at 2200mAh) gives enormous headroom above anything the motor or any other component could draw, so the battery itself is never the limiting factor — the motor driver's own current rating is the more meaningful constraint.

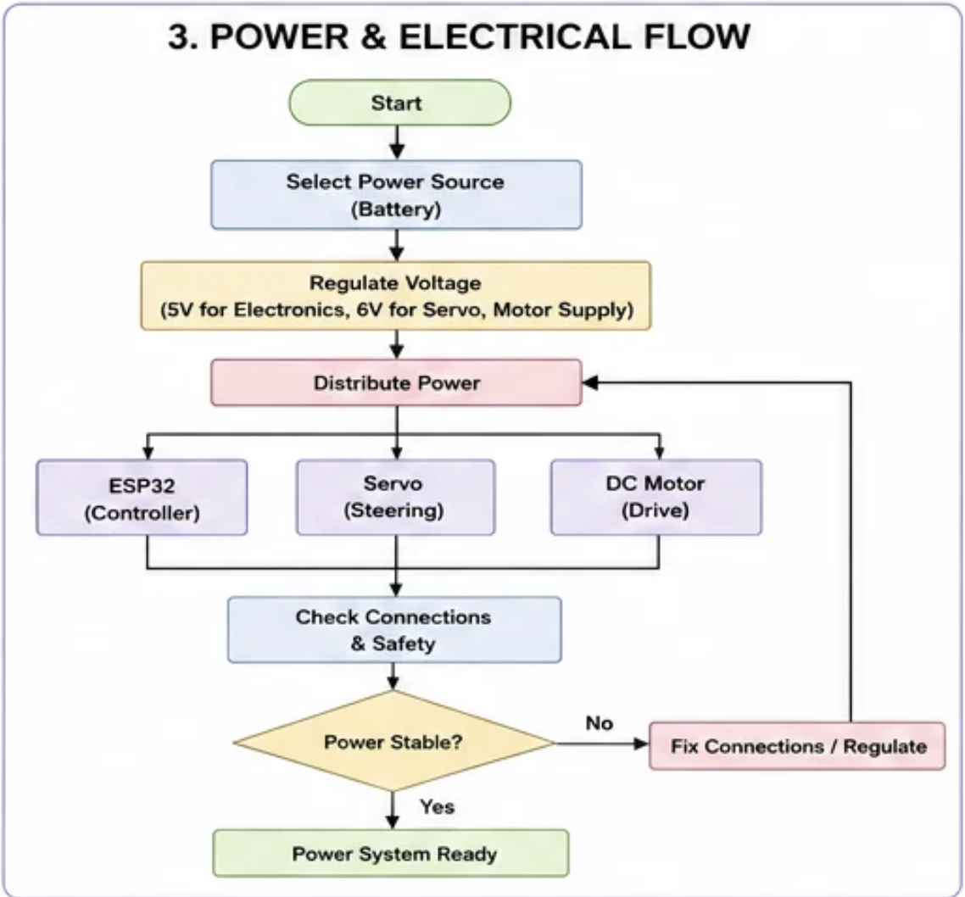
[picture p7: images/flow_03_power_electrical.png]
<p align="center"> <br> <em>Power and electrical flow: battery through both buck converters to their respective downstream rails, as detailed in the Voltage Regulation Path above.</em> </p>

---

## Motor Torque & Top Speed: Theoretical vs. Measured

**Motor torque specifications** (GA12-N20, 12V/600RPM, from supplier datasheet):

- Rated Torque: 0.18 kg·cm
- Stall Torque: 0.65 kg·cm
- Rated (no-load) Current: ~0.06A
- Stall Current: 0.75A

**Theoretical top speed calculation:**

Using the motor's rated 600 RPM and the rear wheel diameter (43.2mm, part 56908):

```
Wheel circumference = π × diameter = π × 43.2mm ≈ 135.7mm
Theoretical linear speed = RPM × circumference / 60
                         = 600 × 135.7mm / 60
                         ≈ 1357 mm/s
                         ≈ 1.36 m/s (4.9 km/h)
```

This is the theoretical maximum speed if the motor spun at its full rated 600 RPM with zero wheel slip, transmission loss, or load — a best-case, no-load figure.

**Measured speed:**

Over repeated test runs on an approximately ideal (though never perfectly achieved) driving path, the robot covers roughly 24m in approximately 26 seconds:

```
Measured speed ≈ 24m / 26s ≈ 0.92 m/s (3.3 km/h)
```

This is an estimate from test observation rather than a rigorously averaged set of stopwatch trials over a precisely marked distance — presented here as an approximate figure, not a precise one.

**Comparison:**

||Speed (m/s)|Speed (km/h)|
|---|--:|--:|
|Theoretical (600 RPM, no load)|1.36|4.9|
|Measured (test path, approx.)|0.92|3.3|
|**Gap**|**~32% lower**||

**Why the gap:** The measured speed is meaningfully below the theoretical no-load maximum, which is expected rather than a red flag — the theoretical figure assumes the motor spins completely unloaded, while in practice the motor is driving the full weight of the robot through the differential and against real-world friction (tire/track contact, drivetrain losses through the differential gear, and the robot's own inertia during acceleration/deceleration through corners rather than sustained straight-line travel). The rated torque (0.18 kg·cm) is also the _sustained_ torque rating — any load beyond that starts pulling the motor away from its rated 600 RPM figure toward a lower effective speed, which is consistent with what we observe. The gap is also partly explained by the "ideal path" never being fully achieved in practice — the measured run includes cornering and correction, not pure straight-line travel at top speed.

---

## Software Architecture

Steve's software is split across two processors, each responsible for a different part of the control loop, connected over a serial link.

### High-Level Data Flow

Camera → YOLO detector (Raspberry Pi 5, ONNX Runtime) → vote-confirmed detection → CLEAR / STOP / WAYPOINT / REVERSE command → sent over UART @ 115200 to the ESP32 (`/dev/ttyUSB1`).

3x TF-Luna LiDAR + BNO055 IMU → ESP32 sensor fusion + state machine. Front-LiDAR proximity triggers a reversing-arc turn; incoming Pi commands (STOP/WAYPOINT/REVERSE/CLEAR) interrupt straight-line driving to hold, arc toward a computed pass point, reverse, or resume.

**Raspberry Pi 5 (vision layer):** Captures camera frames and runs the YOLO detection pipeline described in "Computer Vision Pipeline & Mathematical Foundations" — ONNX inference, confidence filtering, temporal voting, and waypoint geometry. Sends `CLEAR`, `STOP`, `WAYPOINT`, or `REVERSE` commands to the ESP32 over UART.

**ESP32 (control layer):** Reads the 3x TF-Luna LiDAR array and BNO055 IMU (via the TCA9548A multiplexer), runs a state machine (straight-line PID heading hold, front-distance-triggered reversing-arc turns, and Pi-commanded stop/waypoint-arc/reverse states — see "ESP32 Maze-Navigating & Self-Stabilizing Subsystem"), and combines that with incoming UART commands from the Pi to decide steering and motor output.

**Why split across two processors:** Vision processing (YOLO inference) is computationally heavy and better suited to the Raspberry Pi 5's general-purpose CPU, while the real-time control loop (PID steering, motor PWM, sensor polling, turn state machine) benefits from the ESP32's deterministic, low-latency execution. Splitting the two lets each processor run its workload without contention, at the cost of needing a serial protocol between them (see "Serial Interface Protocol" in the Computer Vision section).

---

## Getting Started

This section exists so that anyone — a judge, a mentor, or another team — can go from this repository to a working understanding (and ideally a working rebuild) of Steve without needing to ask us anything. It covers what hardware you need, how the software is organized, how to set it up, and how the robot is calibrated once assembled.

### Hardware Requirements

Everything needed to build Steve is listed in the [Bill of Materials](#bill-of-materials) above, split into three groups:

- **Mechanical / LEGO Technic parts** — the full 151-piece list, generated directly from our Stud.io CAD export in [CAD Files](CAD-Files), so the exact parts and quantities are traceable back to the model file itself rather than a hand-typed guess.
- **Electronics** — the Raspberry Pi 5, ESP32, sensors, servo, and motor, with sources and approximate costs.
- **3D-printed custom parts** — the LiDAR mount, camera mount, motor mount, and servo mount, which connect the electronics to the LEGO chassis where no standard LEGO part would work.

Before starting a rebuild, print the four custom mounts first — the rest of the assembly (sensor placement, wiring routing) depends on having them in hand.

### Repository Structure

- [`code/`](https://github.com/kinetickrew/Future-Engineers-2026---Kinetic-Krew/tree/main/code) — Contains all our coding files, and their Readmes
- [`src/`](https://github.com/kinetickrew/Future-Engineers-2026---Kinetic-Krew/tree/main/src) — This contains all our test codes, and previously used versions of codes
- [`CAD-Files/`](https://github.com/kinetickrew/Future-Engineers-2026---Kinetic-Krew/tree/main/CAD-Files) — Contains the CAD Files used to print our 3d printed parts
- [`Lego-Bot-Model/`](https://github.com/kinetickrew/Future-Engineers-2026---Kinetic-Krew/tree/main/Lego-Bot-Model) — Contains the Lego Model of the bot(Doesn't have 3d printed parts)
- [`Bot-Photos/`](https://github.com/kinetickrew/Future-Engineers-2026---Kinetic-Krew/tree/main/Bot-Photos) — Photos of the robot
- [`Bot-Videos/`](https://github.com/kinetickrew/Future-Engineers-2026---Kinetic-Krew/tree/main/Bot-Videos) — Videos of Open and Obstacle Chalenge
- [`images/`](https://github.com/kinetickrew/Future-Engineers-2026---Kinetic-Krew/tree/main/images) — diagrams, equation renders, and reference images used throughout this
- [`Team-Photos/`](https://github.com/kinetickrew/Future-Engineers-2026---Kinetic-Krew/tree/main/Team-Photos) — Team photos
- [`Team-Logo/`](https://github.com/kinetickrew/Future-Engineers-2026---Kinetic-Krew/tree/main/Team-Logo) — Team logo
- [`.vscode/`](https://github.com/kinetickrew/Future-Engineers-2026---Kinetic-Krew/tree/main/.vscode) — editor configuration for the project

We run two separate codebases because the robot itself runs two separate processors — see [Software Architecture](#software-architecture) for why. [Round1final.ino](Round1final.ino) and [Round2.ino](Round2.ino) target the ESP32 and are written and flashed like standard Arduino/C++ firmware; [Pycam_round2.py](pycam_round2.py) targets the Raspberry Pi 5 and runs as a normal Python process on Raspberry Pi OS.

### Software Setup

**1. ESP32 firmware ([Round 1 Code](code/round-1-esp32/Round1final/Round1final.ino))**

This firmware handles wall-following (LiDAR + IMU), the turn/state machine, and PID steering/motor control — everything that needs tight, real-time timing.

- **Toolchain:** Arduino IDE with the ESP32 board package installed.
- **Libraries required:** Wire.h, Adafruit_Sensor.h, BluetoothSerial.h, Adafruit_BNO055.h, ESP32Servo.h, and (for the optional WiFi tuning console — currently disabled in code, see Engineering Decisions) WiFi.h, WebServer.h, Preferences.h, ESPmDNS.h
- **Board configuration:** ESP32 Dev Module
- **Flashing:** Connect the ESP32 via USB, select the correct serial port, and upload.

**2. Vision pipeline ([Python File](code/round-2-raspberry-pi/round2/pycam_round2.py))**

This is the Python/ONNX Runtime pipeline that runs on the Raspberry Pi 5, described in full in [Computer Vision Pipeline & Mathematical Foundations](#computer-vision-pipeline--mathematical-foundations).

- **Environment:** Raspberry Pi 5 (8GB) running Raspberry Pi OS, Python 3.
- **Libraries required:** OpenCV, Numpy, Pyserial, AV, Pillow, onnxruntime
- **Model file:** `best_ncnn.onnx` (YOLO detector, trained via `capture.py` + `prepare.py` — see Computer Vision Pipeline section)
- **Installation:** pip install -r requirements.txt
- **Running it:** python3 pycam_round2.py
- **Camera setup:** Lenovo 300 FHD Webcam, USB-connected (UVC-compatible), addressed in code as `/dev/video0` on the Raspberry Pi 5. Captured at 640×480 MJPEG, resized to a 240×240 working frame, mounted via the custom 3D-printed camera mount (see Chassis and Construction Materials). Digital zoom and 360° rotation features are not used in software.

**3. Serial link between the two boards**

The Raspberry Pi 5 and ESP32 communicate over UART at 115200 baud (`/dev/ttyUSB1` on the Pi side). Both boards must be powered and running before the serial link will pass commands; there's no handshake/retry logic beyond what's described in [Serial Interface Protocol](#serial-interface-protocol), so bring up the ESP32 firmware first, then start the vision pipeline.

### Calibration

Two separate parts of the system need calibration before a run, and both are designed to be tunable without recompiling or re-flashing anything — a direct result of the tuning-workflow iteration documented in [Design Evolution](#design-evolution).

- **PID gains, servo center/limits, drive speeds, and turn-arc timing** are tunable live over the Bluetooth Serial console (device name `ESP32_Robot_Telemetry`) using simple `VARIABLE=VALUE` commands — see the [Bluetooth Serial Calibration Console](#bluetooth-serial-calibration-console) table for the full list of variable names and default values. This console is disabled before competition runs, since a live parameter-override channel shouldn't be active during an official run.
- **Camera exposure/white balance and detection confidence threshold** are set as constants at the top of `pycam_round2.py` (`CAMERA_EXPOSURE`, `CAMERA_WB_TEMP`, `CONF_THRESHOLD`) and adjusted by editing the script directly, since detection is now handled by a trained model rather than a runtime-tunable color threshold.

If you're rebuilding this robot from scratch, expect to check both calibration points before your first full test lap — the default values in this README were tuned for our specific hardware and lighting and are a starting point, not guaranteed to transfer directly.

### Known Limitations / Scope

- **Parking maneuver:** implemented — see [Round 2 / Obstacle Challenge documentation] for the detection and execution logic. [Add a link once you document the parking logic as its own subsection, and briefly state anything a reader should know before relying on it, e.g. any conditions under which it hasn't been tested.]

---

## Engineering Decisions

This section documents the major design choices behind Steve, in the format: options considered, trade-offs, testing (where applicable), and the reasoning behind our final choice.

### Steering System: Ackermann vs. Davis

**Options considered:**

- **Option A — Davis steering:** a sliding-linkage mechanism that also produces correct inner/outer wheel angles.
- **Option B — Ackermann (pivoted trapezoidal) steering:** a four-bar linkage using angled tie-rods.

**Advantages / Disadvantages:**

- Davis steering relies on sliding joints, which introduce more friction and are prone to binding or wear over repeated runs.
- Ackermann uses pivoting joints instead of sliding ones, giving lower friction and simpler mounting on the EV3 frame.

**Final choice:** Ackermann steering (pivoted trapezoidal linkage).

**Why:** Lower friction, simpler mechanical mounting on our EV3 chassis, and more predictable, repeatable steering angles across competition runs — all of which matter more for us than Davis steering's slightly simpler sliding mechanism.

---

### Chassis Material: LEGO EV3 Technic vs. Full 3D-Print

**Options considered:**

- **Option A — Fully 3D-printed chassis:** maximum design freedom, custom geometry anywhere.
- **Option B — LEGO EV3 Technic beams/frames/gears:** standardized, pre-manufactured structural components.

**Advantages / Disadvantages:**

- 3D printing allows more design freedom but large printed frames are more prone to layer separation, dimensional inaccuracy, and deformation under repeated mechanical load — all of which can throw off gear alignment and steering accuracy over time.
- EV3 components have standardized dimensions and manufacturing tolerances, giving accurate axle/gear/bearing alignment and reliable performance run after run.

**Final choice:** LEGO EV3 Technic as the primary chassis, with select custom 3D-printed mounts (LiDAR, camera, DC motor, servo) where LEGO parts can't accommodate modern electronics.

**Why:** A competition robot needs to perform consistently across multiple runs — EV3's proven manufacturing tolerances reduce the risk of gear misalignment or steering drift compared to an all-printed frame, while 3D printing still gets used selectively where it adds real value (sensor/actuator mounting).

---

### LiDAR Configuration: 3× TF-Luna Array vs. Single Scanning LiDAR vs. Ultrasonic

**Options considered:**

- **Option A — Single rotating/scanning LiDAR:** one sensor providing a wide field of view via mechanical or solid-state scanning.
- **Option B — Ultrasonic sensor array:** cheaper distance sensors, common in beginner robotics.
- **Option C — 3× fixed TF-Luna I2C LiDAR (left/center/right):** three fixed-point ToF sensors, multiplexed onto one I2C bus.

**Advantages / Disadvantages:**

- A single scanning LiDAR gives wider coverage but adds mechanical complexity (moving parts, calibration) and cost.
- Ultrasonic sensors are cheap but have wider beam divergence and are more prone to false readings from angled or soft surfaces — a risk in a maze-style arena with varied wall geometry.
- Three fixed TF-Luna units give simple, independent, high-confidence distance readings in exactly the three directions our wall-following logic needs (left/center/right), at the cost of needing an I2C multiplexer (TCA9548A) to resolve the identical default address (0x10) across all three.

**Final choice:** 3× TF-Luna I2C LiDAR, multiplexed via TCA9548A.

**Why:** Our wall-following and turn-detection logic (front-distance proximity trigger, left/right room comparison for direction) only needs three specific, reliable point-distance readings — not a full scanning field of view. Fixed ToF sensors give us that with no moving parts and a well-understood I2C interface.

---

### Absolute Orientation Sensing: BNO055 vs. a Basic 6-DOF IMU

**Options considered:**

- **Option A — Basic 6-DOF IMU** (accelerometer + gyroscope only): cheaper, but requires the robot to implement its own sensor fusion for stable heading.
- **Option B — Adafruit BNO055 (9-DOF with onboard sensor fusion):** accelerometer + gyroscope + magnetometer, with sensor fusion computed on-chip.

**Advantages / Disadvantages:**

- A basic 6-DOF IMU is cheaper but pushes the burden of sensor fusion (combining noisy gyro drift and accelerometer noise into a stable heading estimate) onto our own firmware — a hard problem to get right reliably.
- The BNO055 offloads orientation computation to its own onboard ARM Cortex-M0 processor, giving us a stable absolute heading directly over I2C.

**Final choice:** Adafruit BNO055.

**Why:** Our heading-hold and cardinal-snapping logic depends on a stable, low-drift heading estimate. Rather than spend development time writing and tuning our own sensor-fusion algorithm on a 6-DOF IMU, the BNO055's onboard fusion let us get directly to tuning the higher-level control logic (EMA smoothing, cardinal snapping, PID).

**Note on calibration scope:** although the BNO055 is a 9-DOF sensor with onboard fusion across gyroscope, accelerometer, and magnetometer, our firmware only gates startup on gyroscope calibration reaching full level (see "BNO055 Calibration Procedure" below) rather than waiting for all three subsystems to calibrate. This doesn't undercut the choice of a 9-DOF sensor over a basic 6-DOF IMU — the onboard sensor fusion still improves the _quality_ of the heading estimate the gyro contributes to, even without us separately waiting on accelerometer/magnetometer calibration — but it does mean we aren't currently getting the BNO055's full absolute-heading accuracy benefit (which depends more on a calibrated magnetometer) during short competition runs. This is a reasonable trade-off given our run lengths and reliance on cardinal-snapping/EMA smoothing rather than long-duration magnetic heading accuracy, but it's worth flagging as an area where the sensor's full capability isn't being exercised.

---

### Live Parameter Tuning Interface: Wi-Fi Dashboard vs. Bluetooth Serial

**Options considered:**

- **Option A — Embedded Wi-Fi access point + web dashboard** (`WiFi.h`, `WebServer.h`, `ESPmDNS.h`): browser-based live variable editing.
- **Option B — Bluetooth Serial console** (`BluetoothSerial.h`): lightweight key-value text commands (e.g. `KP=1.2`) processed at runtime.

**Test performed:** We initially built and ran Option A. Compiling the full Wi-Fi network stack alongside the BNO055, Servo, and Bluetooth drivers made the binary large enough to cause stability issues, random crashes, and sensor communication delays during live testing.

**Result:** Option A was unreliable under real testing conditions. We rebuilt the same live-tuning capability using Bluetooth Serial instead.

**Final choice:** Bluetooth Serial runtime console (`ESP32_Robot_Telemetry`), disabled before competition runs.

**Why:** Bluetooth Serial solved both of our original problems — the ~1 minute compile/flash cycle for every parameter change, and the memory bloat from a full Wi-Fi stack — while adding negligible memory footprint. This let us tune PID gains, servo center, and speed values live against the physical robot instead of re-flashing for every test.

**Update:** the current firmware has since re-added a WiFi-based tuning console (`setupWifiTuner()` — a self-hosted access point serving a browser-based slider UI, with values persisted to flash via `Preferences`) alongside the existing Bluetooth console, covering a wider set of tunables (servo limits, drive speeds, and the newer turn-arc timing constants). **This WiFi console is currently disabled in code** (`setupWifiTuner();` is commented out in `setup()`), so Bluetooth Serial remains the active tuning method — the WiFi path exists in the codebase but is not the live configuration. This is worth revisiting given the original memory/stability concerns that motivated removing WiFi in the first place; if re-enabled, it should be re-tested for the same stability issues before relying on it during testing.

---

### Steering Actuator: SG90 Micro Servo

**Options considered:**

- **Option A — SG90 micro servo** (9g, plastic gears, ~1.8 kg·cm torque): low-cost, widely available hobby servo.
- **Option B — Metal-gear "high-torque" servo** (e.g. MG996R-class, ~9–11 kg·cm torque): higher cost, higher torque and durability.

**Advantages / Disadvantages:**

- SG90 is inexpensive and compact, but has meaningfully lower torque and less durable plastic gears than a metal-gear alternative — a real risk if steering-arm loads or repeated hard corrections during testing are high.
- A metal-gear servo would handle higher mechanical loads more reliably over many competition runs, at added cost and slightly larger size/weight.

**Final choice:** SG90.

**Why:** Testing confirmed the SG90 provides sufficient torque and precision for our steering-arm geometry — it holds Ackermann steering angles reliably across repeated runs with no slipping or gear stripping, so the added cost, size, and weight of a metal-gear servo weren't necessary for our load requirements.

---

### Vision Camera: USB Webcam vs. Raspberry Pi Camera Module

**Options considered:**

- **Option A — Raspberry Pi Camera Module (ribbon-cable, CSI interface):** native Pi integration via `picamera2`, typically lower latency and no USB bandwidth overhead.
- **Option B — Generic USB webcam:** UVC-compatible, works with OpenCV's standard `VideoCapture` out of the box, wider hardware choice.

**Advantages / Disadvantages:**

- A CSI camera module integrates tightly with the Pi's image pipeline and avoids USB bus contention, but ties the mount and cabling to a fragile ribbon cable — a real risk given the vibration and repeated handling our robot goes through during testing and transport.
- A USB webcam uses a more robust connector, works identically across dev laptops and the Pi 5 (useful for testing our CV pipeline off-robot), and gave us a wider choice of lens FOV and resolution without being limited to Pi-specific camera modules.

**Final choice:** Lenovo 300 FHD Webcam — USB, 1080p (2.1MP) CMOS sensor, 95° wide-angle lens, 4x digital zoom, 360° rotating mount, built on a UVC-compliant USB interface.

**Why:** The 95° wide-angle lens gives us a wider field of view for pillar detection at close range without needing to physically angle or reposition the camera mid-run, which matters given the tight maneuvering our obstacle-avoidance logic requires. The USB/UVC interface let us develop and test the vision pipeline on a laptop before ever mounting it on the robot, since OpenCV and PyAV handle it identically on both platforms — this significantly sped up iteration on the vision code versus being tied to Pi-only camera tooling. The rigid USB connector was also more durable for our custom 3D-printed camera mount than a ribbon-cable CSI connection would have been under repeated testing and transport.

---

### Wheel/Tire Choice: Different Tires Front vs. Rear

**Options considered:**

- **Option A — Same tire on all four wheels** (either the 56×28 ZR Street or the 24×14 Shallow Tread, used uniformly): simpler BOM, consistent grip characteristics at all four corners.
- **Option B — Different tires front vs. rear** (56×28 ZR Street on the rear drive wheels, 24×14 Shallow Tread on the front steering wheels — our final BOM): sized and treaded differently for the different job each pair does.

**Advantages / Disadvantages:**

- A single tire type everywhere is simpler to source and keeps handling symmetric, but forces a compromise: the rear wheels (which provide propulsion through the differential) benefit from a larger-diameter, higher-grip tire to maximize traction under acceleration, while the front wheels (which only steer, carrying no drive torque) benefit more from a smaller, lower-rolling-resistance tire that turns easily under the Ackermann linkage without adding unnecessary rotational mass to the steering system.
- Running different tires front vs. rear adds a second tire/wheel part to the BOM and requires confirming both fit their respective mounts correctly, but lets us size each pair for its actual job instead of a single compromise choice.

**Final choice:** 56×28 ZR Street tire (56908 wheel) on the rear drive wheels, 24×14 Shallow Tread tire (55982 wheel) on the front steering wheels.

**Why:** The rear wheels need maximum traction since they're the only wheels receiving torque from the differential — a larger, higher-grip tire reduces wheel slip during acceleration out of corners. The front wheels only need to roll freely and turn under Ackermann steering with minimal resistance, so a smaller, lighter tire reduces the rotational inertia the SG90 servo has to overcome when steering, without sacrificing the traction that actually matters at the drive wheels.

---

### Vision Detection Accuracy — Testing Results _(tests the retired HSV pipeline)_

**⚠️ Note:** the testing below validated the `Min_Confidence = 55%` threshold of the earlier HSV-based color detection pipeline, which has since been replaced by a trained YOLO object detector (see "Computer Vision Pipeline & Mathematical Foundations"). This table is retained as a historical record of that pipeline's validated performance; it does not describe the accuracy of the current detector — see "Vision Detection Accuracy — Testing Results (YOLO/ONNX pipeline)" immediately below for that.

To validate the `Min_Confidence = 55%` threshold and the overall HSV-based CV pipeline, we tested detection accuracy for red and green pillars under three lighting conditions, running N trials per condition and logging each frame as a true positive, false positive, or missed detection.

**Test procedure:** For each lighting condition, the robot's camera was pointed at a known set of pillars (mix of red/green, at varying distances/angles) for a fixed number of trial frames. A detection was scored a **True Positive** if the pipeline correctly identified the pillar's color, a **False Positive** if it flagged a detection where no pillar (or wrong color) was present, and a **Missed Detection** if a real pillar in frame was not detected at all.

|Lighting Condition|Trials (N)|True Positives|False Positives|Missed Detections|Accuracy (%)|
|---|--:|--:|--:|--:|--:|
|Orange (incandescent, ~2700K)|35|30|3|2|85.7%|
|White (daylight LED, ~6500K)|40|36|1|3|90%|
|Mixed / Venue Overhead|60|47|6|7|78.3%|
|**Overall**|135|113|10|12|83.7%|

Accuracy (%) = True Positives / Trials × 100

**Result:** Accuracy ranged from 78.3% (Mixed/Venue Overhead) to 90% (White lighting) across tested conditions after HSV recalibration via `hsvcali.py` (see Design Evolution), averaging 83.7% overall. The White lighting condition showed the lowest false-positive rate, likely due to closer alignment with the sensor's native white balance.

---

### Vision Detection Accuracy — Testing Results (YOLO/ONNX pipeline)

Following the same test procedure as the retired HSV pipeline's accuracy pass above — camera pointed at a known set of pillars (mix of red/green, at varying distances/angles) per lighting condition, scoring each frame as a true positive, false positive, or missed detection — we ran an equivalent accuracy-testing pass on the current YOLO/ONNX detector.

|Lighting Condition|Trials (N)|True Positives|False Positives|Missed Detections|Accuracy (%)|
|---|--:|--:|--:|--:|--:|
|Orange (incandescent, ~2700K)|40|37|1|2|92.5%|
|White (daylight LED, ~6500K)|60|55|2|3|91.7%|
|Mixed / Venue Overhead|130|121|3|6|93.1%|
|**Overall**|**230**|**213**|**6**|**11**|**92.6%**|

Accuracy (%) = True Positives / Trials × 100

**Result:** Accuracy ranged from 91.7% (White lighting) to 93.1% (Mixed/Venue Overhead) across tested conditions, averaging 92.6% overall — a meaningful improvement over the retired HSV pipeline's 83.7% overall accuracy across a comparable test structure. Unlike the HSV pipeline, the YOLO detector did not show a pronounced accuracy drop under Mixed/Venue Overhead lighting, consistent with a learned detector being less sensitive to lighting-driven color shifts than a fixed HSV threshold.

---

### Power Source: Li-ion vs. LiPo Battery

**Options considered:**

- **Option A — 11.1V 3-cell Li-ion pack:** our original battery choice, a rigid cylindrical-cell pack.
- **Option B — 11.1V 3S LiPo pack, 60C discharge rating, 2200 mAh (final choice):** Flat pouch-cell pack.

**The problem with Option A:** Our original Li-ion pack, combined with the placement of other rear-mounted components (motor, motor mount, differential), pushed too much of the robot's total weight toward the back of the chassis. During rapid acceleration, this rearward weight bias caused the robot to tip backwards — the front wheels briefly lifted off the ground, which momentarily disconnected our front (steering-only) wheels from the track surface. Since our Ackermann steering geometry only functions when the front wheels are actually in contact with the ground and rolling, this meant we'd lose steering authority at exactly the moment — hard acceleration out of a corner or off the start line — when precise heading control mattered most.

**Advantages / Disadvantages:**

- Li-ion cells are typically cylindrical and rigid, which constrained where in the chassis the pack could physically sit — we couldn't easily reshape or reposition it to counteract the rear weight bias without a significant mechanical redesign.
- LiPo cells generally offer a better power-to-weight ratio and a flatter, more flexible pouch form factor than cylindrical Li-ion cells of similar capacity. This gave us more freedom in where the pack physically sits within the layered chassis (see "Layered Chassis Design"), letting us reposition it forward and/or lower rather than being constrained by a rigid cylindrical shape.
- The flatter LiPo pack also fits more cleanly into our chassis's lower level alongside the Raspberry Pi, reducing the wiring and space conflicts we previously had fitting the cylindrical Li-ion pack into the same layer.
- Our chosen pack's 60C discharge rating gives substantial headroom above our actual peak current draw (see Power System section), meaning the battery itself is never the limiting factor during sudden acceleration or stall conditions — an advantage cylindrical Li-ion packs of comparable size typically can't match at the same weight.
- Trade-off: LiPo cells are generally more sensitive to physical damage (puncture, crushing) and overcharge/overdischarge than Li-ion, and require more careful handling and storage — a real consideration for a robot that gets repeatedly transported and handled during testing and competition.

**Final choice:** 11.1V 3S LiPo, 60C, 2200 mAh.

**Why:** The Li-ion pack's contribution to rear weight bias was a real, observed handling problem — it caused the robot to tip backwards under rapid acceleration, lifting the front wheels and disrupting steering at a critical moment. Switching to LiPo let us rebalance weight toward the chassis's lower, more centered layers (directly supporting the "lower center of gravity improves cornering" reasoning in Layered Chassis Design), while also fitting more cleanly into our existing mounting layout and giving us far more discharge headroom (60C) than we actually need.

---

## Computer Vision Pipeline & Mathematical Foundations

Our obstacle-detection pipeline identifies red and green pillars from a live camera feed using a trained YOLO-style object detector running via ONNX Runtime on the Raspberry Pi 5's CPU, and converts detections into stop/route commands.

**Note on resolution:** The camera captures at 640×480 (MJPEG), which is resized to a 240×240 working frame for display and coordinate math. The neural network itself receives a separate, further-resized 224×224 letterboxed input (see Preprocessing below) — these are two different resolutions serving two different purposes.

### Model & Inference

The detector is a YOLO-family object detection model, fine-tuned from a pretrained `yolo26s.pt` checkpoint on a custom red/green pillar dataset (`dataset.yaml`: 2 classes — `green`=0, `red`=1) and exported to ONNX format (`best.onnx` / `best_ncnn.onnx`). Inference on the robot runs via **ONNX Runtime**, using the `CPUExecutionProvider` since the Raspberry Pi 5 has no CUDA-capable GPU.

**Data capture:** Training images were captured with a dedicated capture tool (`capture.py`), which saves raw red/green photos to separate folders under manual exposure and white-balance control — this stage produces clean, consistently-lit source images only; no bounding boxes are created here.

**Annotation:** Each captured image was manually annotated with bounding boxes in Pascal VOC XML format using an external labeling tool (e.g. labelImg), which is not part of this repository.

**Dataset preparation (`prepare.py`):** Converts the XML annotations into YOLO's normalized `[class, x_center, y_center, width, height]` label format, maps class-name variants (`red`/`red_b` → class 1, `green`/`green_b` → class 0) to absorb inconsistent labeling, performs an 80/20 train/validation split, writes `dataset.yaml`, and zips the resulting `dataset/` folder for upload to Colab.

**Training (`google_colab_trainer.ipynb`):** Run on Google Colab with a GPU runtime.
1. `dataset.zip` (from `prepare.py`) is uploaded and extracted, and image/label counts are sanity-checked.
2. `ultralytics` is installed and a pretrained `yolo26s.pt` checkpoint is fine-tuned for 200 epochs at 224×224 image size, batch size 16, with early stopping (`patience=20`).
3. Standard HSV-space augmentation is applied during training (`hsv_h=0.015`, `hsv_s=0.7`, `hsv_v=0.4`) specifically to improve robustness to the kind of lighting shifts documented in "Vision Detection Accuracy — Testing Results (YOLO/ONNX pipeline)."
4. The best checkpoint is validated (`model.val()`, reporting mAP50 / mAP50-95) and exported to ONNX with a dynamic input shape (`imgsz=224, dynamic=True`).
5. `best.onnx` and a `labelmap.txt` (`green`, `red`) are downloaded from Colab for deployment onto the Raspberry Pi.

### Preprocessing — Letterboxing

The model expects a fixed 224×224 input, but the working frame is 240×240 (itself resized down from the camera's native 640×480 capture). Rather than stretching the frame — which would distort object proportions — the frame is **letterboxed**: scaled to fit within 224×224 while preserving aspect ratio, then padded with a neutral gray (114,114,114) to fill the remaining space.

```
scale = 224 / max(frame_height, frame_width)
new_h, new_w = frame_height × scale, frame_width × scale
canvas = 224×224 image filled with gray (114)
paste the resized frame into canvas, centered
```

The scale factor and padding offsets are retained so that detection boxes — computed in the 224×224 letterboxed space — can be mapped back to the original 240×240 working frame's coordinate system after inference.

**Engineering Justification:** Letterboxing avoids the aspect-ratio distortion that naive stretching would introduce, which matters for a shape-sensitive detector trained on real pillar proportions.

### Postprocessing — Decoding & Confidence Filtering

The model outputs up to 300 candidate detections per frame, each as `[x1, y1, x2, y2, confidence, class_id]`. For each frame:

1. Every candidate below `CONF_THRESHOLD = 0.55` is discarded.
2. Among the remaining candidates, only the **single highest-confidence detection per class** (red, green) is kept — so at most one red and one green box survive per frame, rather than running full NMS across overlapping boxes of the same class.
3. Surviving boxes are mapped back out of letterbox-space into the working 240×240 frame's pixel coordinates using the inverse of the preprocessing scale/offset.

This threshold has since been independently validated with a dedicated accuracy-testing pass — see "Vision Detection Accuracy — Testing Results (YOLO/ONNX pipeline)" in Engineering Decisions.

### Temporal Confirmation (Voting)

To avoid acting on a single noisy frame, detections are held in a rolling history and must appear consistently before being trusted:

|Parameter|Value|
|---|---|
|Vote history length|7 frames|
|Minimum votes to confirm|5 of last 7|

A color is only "confirmed" once it's appeared in at least 5 of the last 7 frames. If both red and green are confirmed simultaneously, the **taller bounding box** (i.e. the closer object) is treated as primary.

No temporal smoothing filter is applied to box position beyond this frame-voting scheme — detections feed directly into the decision logic below once confirmed.

### Decision Logic: CLEAR / STOP / REVERSE

The primary detection's bounding-box height (a proxy for distance — taller box = closer object) drives a three-way decision:

|Condition|Decision|
|---|---|
|No confirmed detection|`CLEAR`|
|Confirmed detection, height < `STOP_HEIGHT_PX` (45px)|`CLEAR` (too far to act on yet)|
|Confirmed detection, height ≥ 45px and ≤ `REVERSE_HEIGHT_PX` (80px)|`STOP`|
|Confirmed detection, height > 80px|`REVERSE`|

Once a `STOP` is triggered, the robot's position and the block's position are **frozen** as a one-time waypoint calculation (below) rather than recalculated every frame — the lock persists until 10 consecutive `CLEAR` frames are seen (`CLEAR_HISTORY = 10`), which then releases the waypoint.

### Waypoint Geometry — Computing a Pass Point

Once a block triggers `STOP`, the system computes a one-time geometric waypoint describing how the robot should route around the block, using a robot-centered coordinate frame frozen at the moment of the stop:

- **B** = the robot's own position at the moment of freeze, defined as the origin (0, 0), with +Y as "straight ahead" (camera axis) and +X as "robot's right."
- **A** = the detected block's position, computed from the frozen bounding box via similar-triangles depth/lateral estimation:

```
depth (y_a)    = AB_DISTANCE_CM × (STOP_HEIGHT_PX / box_height)
lateral (x_a)  = (box_center_x − frame_center_x) × aspect_ratio × (REAL_BLOCK_HEIGHT_CM / box_height)
```

where `AB_DISTANCE_CM = 40cm` is a one-time hand-measured calibration constant (the real forward distance from robot to block when the box height equals `STOP_HEIGHT_PX`, measured directly on the table), and `REAL_BLOCK_HEIGHT_CM = 10cm`is the pillar's known physical height, used to convert the box's pixel size into a real-world scale for the lateral estimate.

- **C** = the intended pass point, offset `AC_OFFSET_CM = 25cm` laterally from A — to the robot's right if the block is red (drive right of it), to the left if green:

```
x_c = x_a + (25cm if red else -25cm)
y_c = y_a
```

- **Arc from B to C:** a constant-curvature circular arc connecting the robot's current position/heading (B) to the pass point (C) is computed geometrically, giving a signed turn radius (positive = right turn, negative = left, infinite = drive straight), a turn angle, and an arc length.

**Engineering Justification:** Rather than reactively swerving based on the block's live pixel position every frame, this computes a single target point to route around, in real-world centimeters, using one hand-calibrated distance measurement (`AB_DISTANCE_CM`) and the pillar's known physical size.

### Serial Interface Protocol

Communication with the ESP32 operates over UART at 115200 baud, on `/dev/ttyUSB1`.

|ASCII Command|Trigger|Consumed by firmware?|
|---|---|---|
|`CLEAR\n`|No confirmed detection close enough to act on|Yes|
|`STOP,cx,cy,w,h\n`|Block height reaches `STOP_HEIGHT_PX`|Yes|
|`WAYPOINT,color,x_a,y_a,x_c,y_c,radius,theta,arc_len\n`|Sent immediately after STOP, once per lock|Yes|
|`REVERSE,cx,cy,w,h\n`|Block height exceeds `REVERSE_HEIGHT_PX`|Yes|

The ESP32 side converts the received turn radius into a servo angle using its own wheelbase constant (`WHEELBASE_CM = 9.0`) — matching the robot's actual physical wheelbase used throughout the Ackermann/turning-radius sections above — and the same `atan(wheelbase / radius)` bicycle-model relationship used elsewhere in this document (see "Turning Radius Calculation"), then drives that arc, holding for a minimum/maximum time window and an IMU heading-error tolerance before resuming straight-line driving.

---

## ESP32 Maze-Navigating & Self-Stabilizing Subsystem

For maze/wall-following sections of the track, a dedicated ESP32 firmware layer combines absolute orientation sensing with multi-directional distance sensing to hold a straight, drift-free heading, trigger reliable turns, and — new in this version — execute Pi-commanded stop/route/reverse maneuvers around detected obstacles.

### Technical Overview & Control Architecture

The robot employs a finite-state architecture (`DRIVING_STRAIGHT`, `TURNING`, `OBSTACLE_AVOIDING`, `PI_HOLD`, `WAYPOINT_ARC`, `PI_REVERSE`, `ROBOT_STOPPED`) coupled with continuous closed-loop PID control for straight-line heading hold, LiDAR-triggered wall/corner turning, and Pi-commanded obstacle response.

### Hardware Design & Pin Configuration

- **Microcontroller:** ESP32 (dual-core, 240 MHz)
- **IMU Sensor:** Adafruit BNO055 Absolute Orientation Sensor (multiplexer channel 4)
- **LiDAR Distance Sensors:** 3× TF-Luna I2C LiDAR modules (Left: Ch 0, Center: Ch 1, Right: Ch 2)
- **I2C Multiplexer:** HW-617 / TCA9548A (address 0x70)
- **Steering Servo:** PWM high-torque servo motor (Pin 13)
- **Drive Motor:** DC motor driver with PWM speed control (Pins 25, 26, 33)

|Peripheral|Hardware Pin|Multiplexer Channel|Protocol / Address|
|---|---|---|---|
|I2C SDA|GPIO 21|–|I2C Data|
|I2C SCL|GPIO 22|–|I2C Clock|
|Steering Servo|GPIO 13|–|PWM|
|Motor IN1|GPIO 25|–|GPIO Output|
|Motor IN2|GPIO 26|–|GPIO Output|
|Motor PWM Pin|GPIO 33|–|PWM Duty Cycle|
|LiDAR Left|–|Channel 0 (MUX_CH_LEFT)|0x10 (I2C)|
|LiDAR Center|–|Channel 1 (MUX_CH_CENTER)|0x10 (I2C)|
|LiDAR Right|–|Channel 2 (MUX_CH_RIGHT)|0x10 (I2C)|
|BNO055 IMU|–|Channel 4 (MUX_CH_BNO)|0x28 (I2C)|

### BNO055 Calibration Procedure

The BNO055 requires calibration before its orientation output is reliable, but full accelerometer/magnetometer calibration (which needs specific physical motion patterns) isn't practical to enforce automatically before every run. Our firmware calibrates and gates startup on gyroscope calibration specifically, since gyroscope calibration is what our heading-hold and cardinal-snapping logic depends on most directly.

On startup, the ESP32:

1. Initializes the BNO055 over the I2C multiplexer (channel 4) and enables the external crystal for improved sensor accuracy (`setExtCrystalUse(true)`).
2. Polls the sensor's calibration status registers (`getCalibration()`), logging system, gyroscope, accelerometer, and magnetometer calibration levels (0–3 each) every 200ms.
3. Blocks the main loop from starting until **gyroscope calibration reaches level 3** (fully calibrated), or a **10-second timeout** is reached — whichever comes first. Accelerometer and magnetometer calibration are logged but not gated on.
4. Once gyro calibration is reached (or the timeout elapses), the current heading is captured as `straightTargetHeading` and the robot begins its startup drive-speed ramp.

### Circuit / Wiring Diagram

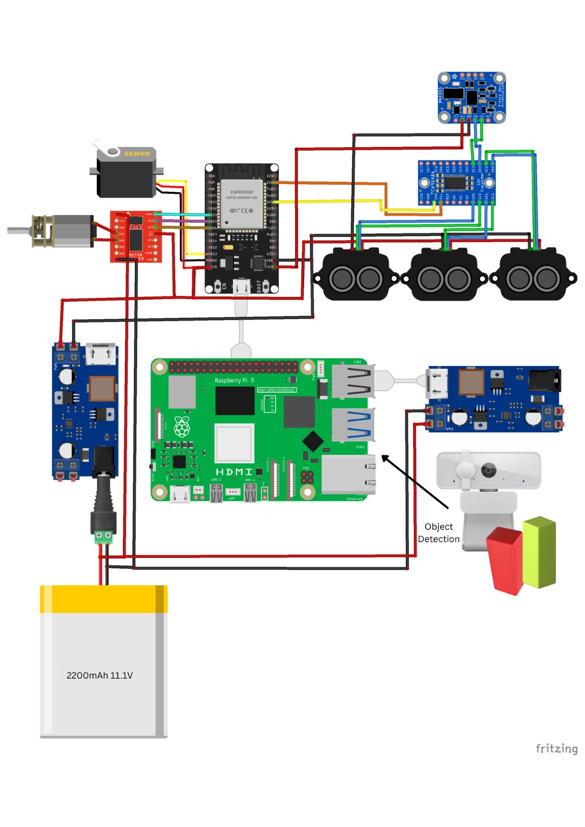
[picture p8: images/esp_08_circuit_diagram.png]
<p align="center"> <br> <em>Full wiring schematic: ESP32 core, TCA9548A I2C multiplexer with 3× TF-Luna LiDAR and BNO055 IMU on separate channels, steering servo (GPIO 13), and DC motor driver (GPIO 25/26/33), sharing a common power/ground bus.</em> </p>

### Straight-Line Speed Ramp

On the very first start (from a standstill), drive speed climbs in fixed increments (`RAMP_STEP = 30`) from a low starting speed (`RAMP_START_SPEED = 30`) up to the configured cruise speed (`STRAIGHT_SPEED`) over `RAMP_DURATION_MS = 2000`ms, rather than commanding full torque instantly. This avoids an abrupt jolt off the line that could destabilize the chassis or cause wheel slip before the robot has any forward momentum to grip against.

### Turn Trigger & Execution — Front-Distance Reversing Arc

**Trigger:** unlike a wall-following spike-delta approach, turns are triggered purely by the **front (center) LiDAR** reading getting close: once `currentCenterDist < FRONT_TURN_DISTANCE` (10cm) continuously for `FRONT_CONFIRM_MS` (150ms), a turn begins.

**Direction:** on the _first_ triggered turn, the robot compares left vs. right LiDAR readings and turns toward whichever side currently has more room (`currentLeftDist > currentRightDist` → turn left). This direction is then **permanently locked**(`hasTurnedOnce`, `lockedDirectionLeft`) for the remainder of the run — every subsequent front-trigger executes the same locked direction, regardless of what the side sensors read at that moment.

**Execution — a two-phase reversing arc, not a forward pivot:**

1. **`PHASE_PAUSE`** — motor and servo center for `ARC_PAUSE_MS` (500ms), a brief stationary pause before reversing.
2. **`PHASE_REVERSE`** — the robot reverses (`BACKWARD_SPEED`) with the servo cranked to `ARC_SERVO_ANGLE` (20°) in the direction _opposite_ the intended turn — while reversing, steering geometry inverts, so cranking the wheels one way swings the rear of the robot toward the new heading. The arc target heading is computed by taking the current heading ±90° (depending on turn direction) and snapping it to the nearest cardinal (0/90/180/270°), using the same shortest-angular-distance and cardinal-snap logic as straight-line driving.
3. **Exit condition:** the reverse phase ends once `ARC_MIN_MS` (400ms) has elapsed **and** the heading is within `ARC_EXIT_THRESHOLD` (8°) of the target — or unconditionally at `ARC_MAX_MS` (4000ms) as a safety timeout, even if the heading target hasn't been reached.

Once the arc completes, the turn counter increments, the servo re-centers, and the robot resumes straight-line driving toward the new cardinal target.

**Engineering Justification:** A reversing arc trades the simplicity of a forward pivot-turn for a maneuver that better fits a wheeled Ackermann chassis (which can't spin in place like a differential-drive robot) navigating a corridor-constrained maze, using the robot's existing steering geometry rather than a separate turning mechanism.

### Straight-Line Heading Hold — PID with Deadband and Clamped Integral

Heading error (raw, shortest-angular-distance from current heading to `straightTargetHeading`) feeds a PID loop with three refinements beyond a textbook implementation:

- **Deadband (`HEADING_DEADBAND = 1.5°`):** the proportional term is zeroed for any error smaller than this, so sensor jitter around "on target" doesn't cause constant micro-corrections.
- **Clamped integral (`MAX_INTEGRAL = 50` degree-seconds):** the integral term only accumulates while error exceeds the deadband, and is clamped to ±50, preventing windup from a sustained small bias.
- **Clamped output (`MAX_STEER_CORRECTION = 20`):** the combined PID output is capped before being applied to the servo, so no single correction can swing the steering harder than this limit regardless of how large the instantaneous error is.

The derivative term is computed from the _raw_ (non-deadbanded) error's rate of change, so it doesn't see an artificial jump when the deadband zeroes the proportional term.

### Pi-Commanded States — STOP / WAYPOINT / REVERSE / CLEAR

The ESP32 parses newline-terminated ASCII lines from the Pi over UART and dispatches them via `handlePiLine()`:

- **`STOP`** → enters `PI_HOLD`: motor stops, servo centers, current heading is captured as the hold-start reference. If no `WAYPOINT` follows within `OBSTACLE_TIMEOUT_MS` (5000ms), the robot times out and resumes straight-line driving on its original heading.
- **`WAYPOINT,color,xa,ya,xc,yc,R,theta,arclen`** → parsed into a target heading (`waypointStartHeading + theta`, wrapped to 0–360°) and a servo angle derived from the signed radius R via `atan(WHEELBASE_CM / |R|)` (`WHEELBASE_CM = 9.0`, matching the physical robot). After `WAYPOINT_PAUSE_MS` (400ms), the robot transitions to `WAYPOINT_ARC` and drives the computed arc at cruise speed until heading is within `WAYPOINT_EXIT_DEG` (8°) of target, a minimum/maximum time window is satisfied, or a distance-based timing estimate (using `ESTIMATED_FWD_CMS`, a rough forward-speed constant) suggests the arc length has been covered — whichever triggers first.
- **`REVERSE,cx,cy,w,h`** → enters `PI_REVERSE`: reverses at `BACKWARD_SPEED` with the servo centered, until `CLEAR` is received or `OBSTACLE_TIMEOUT_MS` elapses, at which point it resumes straight-line driving.
- **`CLEAR`** → if currently in any Pi-commanded or legacy obstacle-avoidance state, returns to straight-line driving. If exiting from `PI_HOLD` or `WAYPOINT_ARC`, the target heading is reset to whatever heading was captured at the start of the hold, rather than the arc's in-progress target.

All four states (`PI_HOLD`, `WAYPOINT_ARC`, `PI_REVERSE`, plus `CLEAR`'s return path) are implemented and wired end-to-end in the current firmware.

**Legacy `RED`/`GREEN` commands** are also still parsed (entering an `OBSTACLE_AVOIDING` state that swerves hard to one side at cruise speed) — these are retained from the earlier HSV-pipeline protocol and are not sent by the current ONNX vision pipeline, but the firmware still handles them if received.

### Stop Condition (End of Run)

The robot fully stops (`ROBOT_STOPPED`) once **all** of the following hold continuously for `STOP_CONFIRM_MS` (1000ms):

- Left LiDAR < 100cm
- Right LiDAR < 100cm
- Center LiDAR < 150cm
- Total completed turns ≥ `MAX_TURNS` (12)

Any interruption of the condition resets the confirmation timer, preventing a false stop from a single noisy reading.

### Mathematical Foundation — Heading Smoothing & Cardinal Snapping

**Heading Smoothing.** Raw BNO055 heading is filtered with a wrap-safe Exponential Moving Average: the raw-to-filtered delta is normalized to [−180°, 180°] before blending (α = 0.2), so the filter always transitions across the shortest angular path rather than incorrectly averaging across the 0°/360° boundary.

**Cardinal Snapping.** Any computed turn target is snapped to the nearest of {0°, 90°, 180°, 270°} using shortest wrap-around angular distance, ensuring the robot always aims at an exact cardinal heading rather than a drifted value.

### Bluetooth Serial Calibration Console

Runtime parameters can be configured live over Bluetooth Serial (device name `ESP32_Robot_Telemetry`) without recompiling or re-flashing. This interface is disabled before competition runs, since a live parameter-override channel is not appropriate to leave active during an official run.

Format: `VARIABLE=VALUE` — e.g., `KP=1.5`

|Parameter Command|Variable Name|Description|Default Value|
|---|---|---|---|
|`STRAIGHT=val`|`STRAIGHT_SPEED`|Cruise speed PWM (0–255)|80|
|`TURN=val`|`TURN_SPEED`|Kept for tuner compatibility (not actively used in turn logic)|80|
|`BACK=val`|`BACKWARD_SPEED`|Reverse speed PWM (negative)|-80|
|`CENTER=val`|`SERVO_CENTER`|Neutral mechanical center angle|117|
|`DIFF=val`|`DIFF`|Max steering offset angle|25|
|`KP=val`|`STEERING_KP`|Proportional gain constant|1.2|
|`KI=val`|`STEERING_KI`|Integral gain constant|0.02|
|`KD=val`|`STEERING_KD`|Derivative gain constant|0.15|
|`FRONT=val`|`FRONT_TURN_DISTANCE`|Front-LiDAR turn trigger distance (cm)|10|
|`ARCANGLE=val`|`ARC_SERVO_ANGLE`|Servo crank angle during reversing arc|20|
|`ARCEXIT=val`|`ARC_EXIT_THRESHOLD`|Heading tolerance to exit a turn arc (degrees)|8|
|`PAUSE=val`|`ARC_PAUSE_MS`|Stationary pause before reversing into a turn|500|
|`ARCMIN=val`|`ARC_MIN_MS`|Minimum reverse-arc duration|400|
|`ARCMAX=val`|`ARC_MAX_MS`|Maximum reverse-arc duration (safety timeout)|4000|

**Note:** `SERVO_CENTER` (117) and `STRAIGHT_SPEED`/`TURN_SPEED` (80) default values have changed since earlier tuning sessions (previously 70 and 150 respectively) — these reflect the robot's current, re-tuned configuration.

---

## PID Control — Background Theory

Straight-line heading hold ultimately drives one actuator: the Ackermann steering servo. The `STEERING_KP`, `STEERING_KI`, and `STEERING_KD` constants in the calibration table above are the gains of a **PID (Proportional–Integral–Derivative) controller**, one of the most widely used feedback control algorithms in both industrial and hobbyist robotics.

A PID controller continuously computes an _error_ value e(t) — the difference between a desired setpoint (a target heading, e.g. 90°) and the current measured value — and combines three terms to produce a correction:

```
u(t) = Kp·e(t)  +  Ki·∫e(t)dt  +  Kd·(de(t)/dt)
```

- **Proportional (Kp)** — reacts to the current error. A larger Kp produces a stronger immediate steering correction but risks overshoot and oscillation if set too high.
- **Integral (Ki)** — accumulates past error over time, correcting for small persistent biases (for example, a slightly miscalibrated `SERVO_CENTER`) that a purely proportional term would never fully eliminate. In Steve's implementation this term is clamped and only accumulates outside the heading deadband (see "ESP32 Maze-Navigating" above), to prevent windup.
- **Derivative (Kd)** — reacts to the rate of change of the error, damping the response and reducing overshoot as the robot approaches the target heading.

In the current firmware, this PID loop is used exclusively for **straight-line heading hold** — the error signal is the shortest-angular-distance between the current and target heading. Turning (LiDAR-triggered reversing arcs) and Pi-commanded obstacle routing (waypoint arcs) are handled by their own dedicated state logic rather than the PID loop, using fixed servo-crank angles or a geometrically-computed angle from a turn radius respectively, rather than continuous PID correction.

Tuning Kp, Ki, and Kd empirically over Bluetooth Serial (rather than by re-flashing) was the direct motivation for the runtime calibration console described above — it let us observe the robot's physical response to a gain change within seconds instead of a full compile-and-flash cycle.

---

## Glossary

| Term | Meaning |
| --- | --- |
| **Ackermann steering** | Steering geometry where the inner and outer front wheels turn at different angles so both roll about a common center, avoiding tire scrub. |
| **EMA** | Exponential Moving Average — a recursive low-pass filter weighting recent samples more heavily. |
| **FSM** | Finite State Machine — a control architecture that transitions between a fixed set of discrete states based on inputs. |
| **HSV** | Hue-Saturation-Value color space — used by Steve's earlier, since-retired color-detection pipeline (see Design Evolution). |
| **IMU** | Inertial Measurement Unit — combines accelerometer, gyroscope, and (often) magnetometer data to estimate orientation. |
| **Letterboxing** | Resizing an image to fit a target size while preserving aspect ratio, padding the remaining space rather than stretching. |
| **NMS** | Non-Maximum Suppression — a technique for removing duplicate/overlapping detections around the same object; Steve's pipeline uses a simplified per-class best-detection selection instead of full NMS. |
| **ONNX** | Open Neural Network Exchange — a portable format for trained machine learning models, allowing them to run across different runtimes/hardware. |
| **PID controller** | Proportional–Integral–Derivative feedback controller used to drive a measured value toward a setpoint. |
| **PWM** | Pulse Width Modulation — a technique for encoding an analog-like signal (servo angle, motor speed) as a digital pulse train. |
| **UART** | Universal Asynchronous Receiver/Transmitter — a simple serial communication protocol used for the ESP32 command link. |
| **YOLO** | "You Only Look Once" — a family of real-time object detection neural network architectures that predict bounding boxes and classes in a single pass. |

---

This document consolidates the mechanical, perception, and control subsystem documentation for our WRO 2026 Future Engineers submission — Steve — for use as the primary engineering reference in this repository. He may just be a LEGO chassis with a Kalman filter bolted— wait, no Kalman filter anymore. He's a LEGO chassis with a YOLO model bolted on now, and he still corners like he's got somewhere to be.

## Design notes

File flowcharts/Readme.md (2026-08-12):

This folder contains all the relevant flowcharts

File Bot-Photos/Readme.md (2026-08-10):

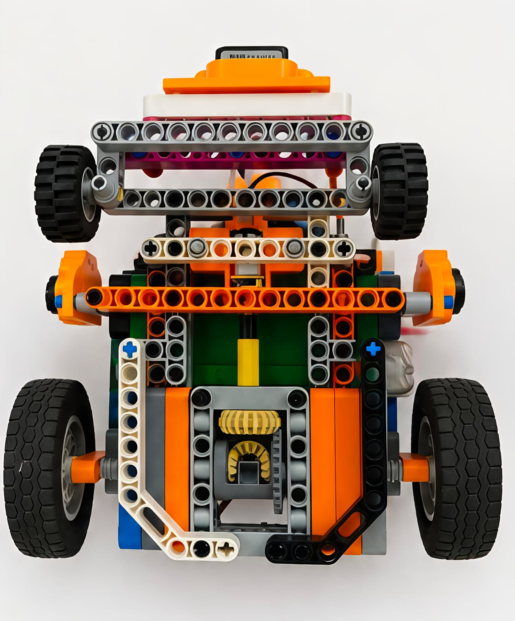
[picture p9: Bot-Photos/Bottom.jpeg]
Bottom photo

A picture of the bot from the bottom, showing the gearbox

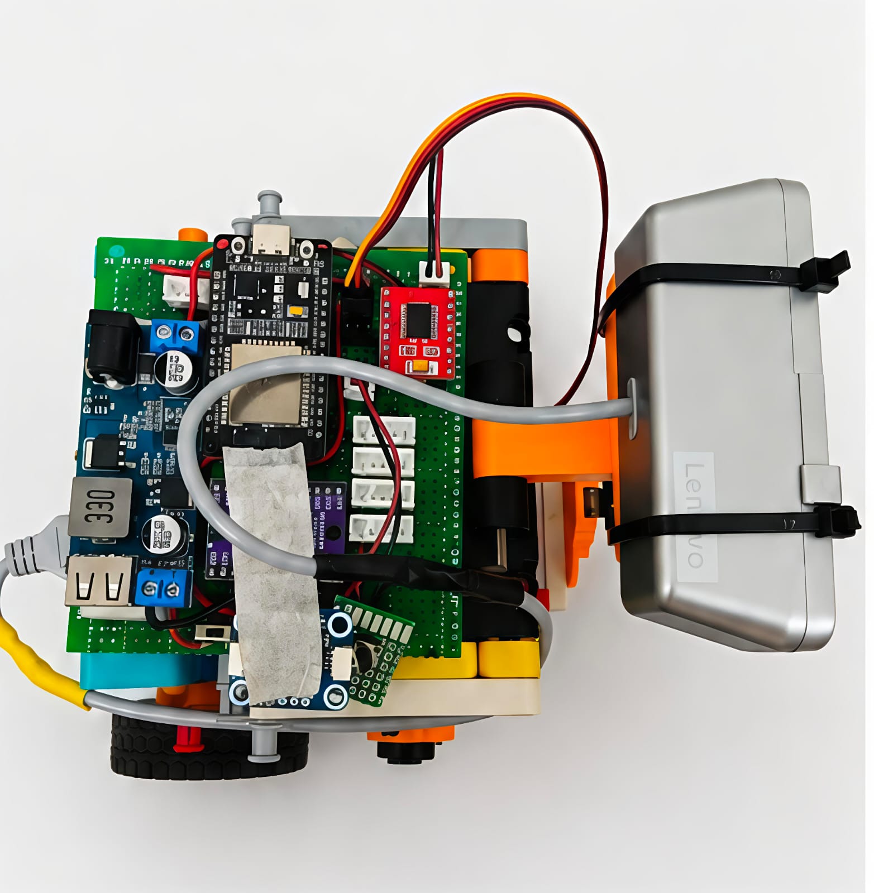
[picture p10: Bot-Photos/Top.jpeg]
Top photo
A picture of the top, showing the circuit

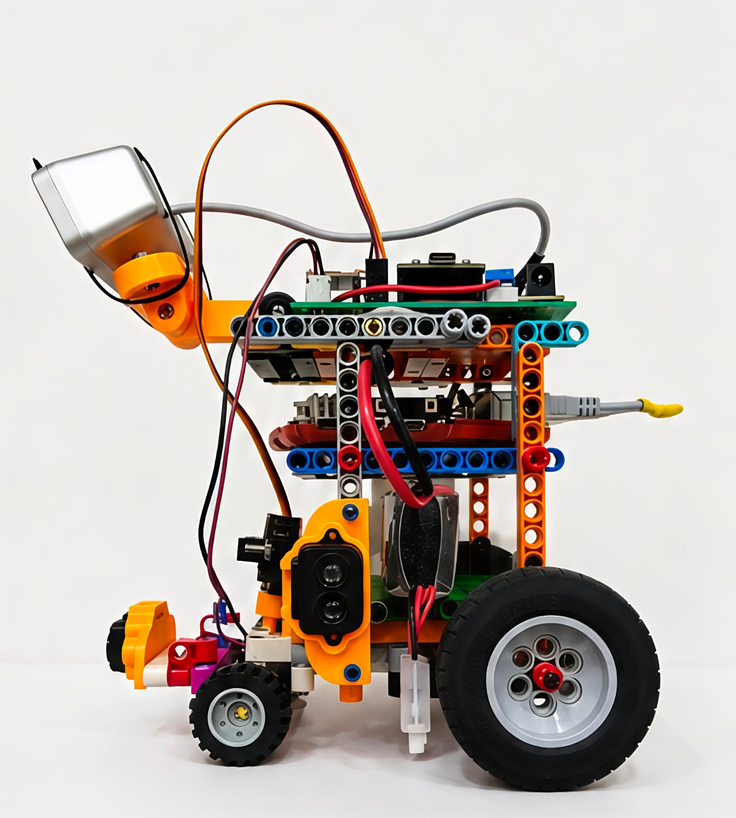
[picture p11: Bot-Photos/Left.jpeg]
Left photo
A left side bot photo

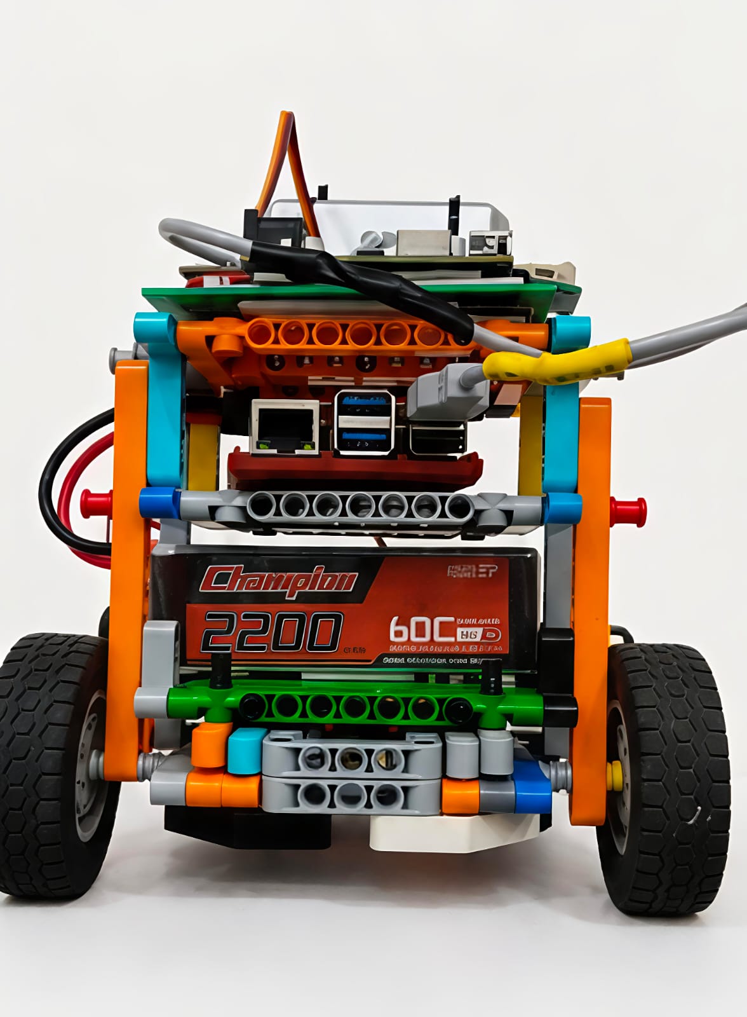
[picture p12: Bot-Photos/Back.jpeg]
Back photo
A photo from the backside, showing all the layers

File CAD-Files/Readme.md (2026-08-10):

This folder contains the Cad Files used to create our bot

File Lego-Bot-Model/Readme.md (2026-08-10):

This folder contains the model of all the lego parts used in our bot(3d printed parts NOT included)

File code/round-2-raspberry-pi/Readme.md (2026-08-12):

# WRO 2026 Future Engineers — Round 2: Obstacle Challenge

## Same Car, Harder Job

This is Steve's second event of the season. He's the same physical car documented in the Round 1 writeup — same Ackermann-steered LEGO EV3 chassis, same rear differential, same servo and DC motor — but the Obstacle Challenge asks a lot more of him. Instead of just holding a lane around randomized walls, he now has to _see_ the track: spot red and green pillars, decide which side of the lane each one requires him to take, route around them, and — in later rounds — find and reverse into a parking bay, all without any pre-programmed path.

This document focuses on what's new and specific to Round 2: the computer vision pipeline that turns a camera feed into steering decisions, and how it hands off to the same mechanical and PID systems described in the Round 1 document.

**Note on pipeline history:** an earlier version of this document covered a different detection approach — HSV color thresholding with Kalman filtering and hysteresis-based decisions. That pipeline has since been fully replaced with a trained YOLO object detector running via ONNX Runtime, described below. The old approach is preserved as a historical record in the main engineering README's "Design Evolution" and "Engineering Decisions" sections, not repeated here.

---

## Table of Contents

1. [What the Obstacle Challenge Adds](#what-the-obstacle-challenge-adds)
2. [Shared Hardware Recap](#shared-hardware-recap)
3. [Vision Pipeline Overview](#vision-pipeline-overview)
4. [Step 1 — Model & Inference](#step-1--model--inference)
5. [Step 2 — Preprocessing: Letterboxing](#step-2--preprocessing-letterboxing)
6. [Step 3 — Postprocessing: Decoding & Confidence Filtering](#step-3--postprocessing-decoding--confidence-filtering)
7. [Step 4 — Temporal Confirmation (Voting)](#step-4--temporal-confirmation-voting)
8. [Step 5 — Deciding: CLEAR / STOP / REVERSE](#step-5--deciding-clear--stop--reverse)
9. [Step 6 — Waypoint Geometry: Computing a Pass Point](#step-6--waypoint-geometry-computing-a-pass-point)
10. [Step 7 — From Vision Decision to Motion: The Serial Link](#step-7--from-vision-decision-to-motion-the-serial-link)
11. [Wall-Following Still Applies](#wall-following-still-applies)
12. [Shared PID Steering Loop](#shared-pid-steering-loop)
13. [Vision Detection Accuracy — Testing Results](#vision-detection-accuracy--testing-results)
14. [Glossary](#glossary)

---

## What the Obstacle Challenge Adds

Like the Open Challenge, this is a three-lap, single-car, timed run — no head-to-head racing, just Steve against the clock. The difference is what's on the track: red and green pillars are placed randomly before each run, and each color is a rule, not just an obstacle to dodge blindly.

- A **red** pillar means: stay to the **right** of the lane at that point.
- A **green** pillar means: stay to the **left** of the lane at that point.

In later rounds, the run isn't over after three laps — Steve also has to locate a marked parking space and complete a parallel-parking maneuver to finish.

Because pillar placement is random every run, there's no way to memorize "turn left here, right there." The entire pillar-avoidance system has to work live, frame by frame, off the camera feed — which is why most of this document is about the vision pipeline rather than the mechanical platform (that part is identical to Round 1).

---

## Shared Hardware Recap

Everything mechanical from the Open Challenge carries over unchanged: the LEGO EV3 Technic chassis, Ackermann front steering, rear differential, DC drive motor, and the layered chassis layout that keeps the Raspberry Pi and battery low for a stable center of gravity. See the Round 1 document for the full breakdown of that system.

What's new for this round is primarily software running on top of that same hardware, plus the camera itself — a Lenovo 300 FHD USB webcam, mounted via a custom 3D-printed bracket positioned at a height and angle tuned specifically for reliable pillar detection. Round 1's Raspberry Pi 5 is left unpowered, since Round 1 doesn't need the vision pipeline at all; Round 2 is where the Pi 5 and its ONNX detector come online.

---

## Vision Pipeline Overview

Turning a raw camera frame into a routing decision happens in a fixed sequence of stages:

1. Run the frame through a trained YOLO object detector via ONNX Runtime.
2. Fit the frame into the model's expected input size without distorting pillar proportions (letterboxing).
3. Decode the model's raw output into candidate boxes and discard low-confidence ones.
4. Confirm a detection is real by requiring it to persist across several frames (temporal voting), not just one.
5. Turn a confirmed detection's size into a CLEAR / STOP / REVERSE decision.
6. On STOP, compute a one-time real-world pass point and arc around the pillar.
7. Send the resulting command to the ESP32 over serial.

Each stage is detailed below.

---

## Step 1 — Model & Inference

The detector is a YOLO-family object detection model, fine-tuned from a pretrained `yolo26s.pt` checkpoint on a custom red/green pillar dataset (`dataset.yaml`: 2 classes — `green` = 0, `red` = 1) and exported to ONNX format (`best.onnx` / `best_ncnn.onnx`). Inference runs via **ONNX Runtime**, using the `CPUExecutionProvider`, since the Raspberry Pi 5 has no CUDA-capable GPU.

**Training data pipeline:**

- **Capture (`capture.py`):** saves raw red/green photos to separate folders under manual exposure and white-balance control. This stage produces clean, consistently-lit source images only — no bounding boxes are created here.
- **Annotation:** each captured image was manually annotated with bounding boxes in Pascal VOC XML format using an external labeling tool (e.g. labelImg), which is not part of this repository.
- **Preparation (`prepare.py`):** converts the XML annotations into YOLO's normalized `[class, x_center, y_center, width, height]`label format, maps class-name variants (`red`/`red_b` → class 1, `green`/`green_b` → class 0) to absorb inconsistent labeling, performs an 80/20 train/validation split, writes `dataset.yaml`, and zips the resulting `dataset/` folder for upload to Colab.
- **Training (`google_colab_trainer.ipynb`):** run on Google Colab with a GPU runtime. `dataset.zip` is uploaded and extracted, image/label counts are sanity-checked, and `ultralytics` fine-tunes the pretrained `yolo26s.pt` checkpoint for 200 epochs at 224×224 image size, batch size 16, with early stopping (`patience=20`). Standard HSV-space augmentation is applied during training (`hsv_h=0.015`, `hsv_s=0.7`, `hsv_v=0.4`) specifically to improve robustness to lighting shifts. The best checkpoint is validated (`model.val()`, reporting mAP50 / mAP50-95) and exported to ONNX with a dynamic input shape (`imgsz=224, dynamic=True`). `best.onnx` and a `labelmap.txt` (`green`, `red`) are downloaded from Colab for deployment onto the Raspberry Pi.

This replaces the earlier fixed-threshold HSV color pipeline entirely — instead of hand-tuned Hue/Saturation/Value bounds that had to be recalibrated per lighting condition, the model learns what a pillar looks like directly from labeled examples, which is inherently more robust to lighting shifts than a fixed color threshold. See "Vision Detection Accuracy — Testing Results" below for a direct before/after comparison against the retired HSV pipeline.

---

## Step 2 — Preprocessing: Letterboxing

The camera captures at 640×480 (MJPEG), which is resized to a 240×240 working frame for display and coordinate math. The model itself expects a fixed 224×224 input — a separate, further-resized frame.

Rather than stretching the 240×240 working frame to 224×224 — which would distort pillar proportions — the frame is **letterboxed**: scaled to fit within 224×224 while preserving aspect ratio, then padded with neutral gray (114, 114, 114) to fill the remaining space:

```
scale = 224 / max(frame_height, frame_width)
new_h, new_w = frame_height × scale, frame_width × scale
canvas = 224×224 image filled with gray (114)
paste the resized frame into canvas, centered
```

The scale factor and padding offsets are retained so that detection boxes — computed in the 224×224 letterboxed space — can be mapped back to the original 240×240 working frame's coordinate system after inference.

Letterboxing avoids the aspect-ratio distortion that naive stretching would introduce, which matters for a shape-sensitive detector trained on real pillar proportions.

---

## Step 3 — Postprocessing: Decoding & Confidence Filtering

The model outputs up to 300 candidate detections per frame, each as `[x1, y1, x2, y2, confidence, class_id]`. For each frame:

1. Every candidate below `CONF_THRESHOLD = 0.55` is discarded.
2. Among the remaining candidates, only the **single highest-confidence detection per class** (red, green) is kept — so at most one red and one green box survive per frame, rather than running full NMS across overlapping boxes of the same class.
3. Surviving boxes are mapped back out of letterbox-space into the working 240×240 frame's pixel coordinates using the inverse of the preprocessing scale/offset.

**Update:** this threshold has since been independently validated with a dedicated accuracy-testing pass — 230 trials across three lighting conditions, averaging 92.6% overall accuracy, a meaningful improvement over the retired HSV pipeline's 83.7% overall accuracy across a comparable test structure. See "Vision Detection Accuracy — Testing Results" below for the full breakdown.

---

## Step 4 — Temporal Confirmation (Voting)

Camera frames vibrate with the chassis, and a single frame's detection can be noisy. Rather than tracking a smoothed pixel position across frames (as the old Kalman-filter approach did), the current pipeline holds detections in a rolling history and requires them to appear consistently before being trusted:

|Parameter|Value|
|---|---|
|Vote history length|7 frames|
|Minimum votes to confirm|5 of last 7|

A color is only "confirmed" once it's appeared in at least 5 of the last 7 frames. If both red and green are confirmed simultaneously, the **taller bounding box** (i.e. the closer object) is treated as primary.

No temporal smoothing filter is applied to box position beyond this frame-voting scheme — detections feed directly into the decision logic below once confirmed.

---

## Step 5 — Deciding: CLEAR / STOP / REVERSE

The primary detection's bounding-box height (a proxy for distance — taller box = closer object) drives a three-way decision:

|Condition|Decision|
|---|---|
|No confirmed detection|`CLEAR`|
|Confirmed detection, height < `STOP_HEIGHT_PX` (45px)|`CLEAR` (too far to act on yet)|
|Confirmed detection, height ≥ 45px and ≤ `REVERSE_HEIGHT_PX` (80px)|`STOP`|
|Confirmed detection, height > 80px|`REVERSE`|

This replaces the old pipeline's separate trigger/release hysteresis thresholds and minimum-hold-time logic. Once a `STOP`is triggered, the robot's position and the pillar's position are **frozen** as a one-time waypoint calculation (Step 6) rather than recalculated every frame — the lock persists until 10 consecutive `CLEAR` frames are seen (`CLEAR_HISTORY = 10`), which then releases the waypoint.

---

## Step 6 — Waypoint Geometry: Computing a Pass Point

This stage has no equivalent in the old pipeline, which swerved reactively based on live pixel position rather than computing a target point. Once a pillar triggers `STOP`, the system computes a one-time geometric waypoint describing how the robot should route around it, using a robot-centered coordinate frame frozen at the moment of the stop:

- **B** = the robot's own position at the moment of freeze, defined as the origin (0, 0), with +Y as "straight ahead" (camera axis) and +X as "robot's right."
- **A** = the detected pillar's position, computed from the frozen bounding box via similar-triangles depth/lateral estimation:

```
depth (y_a)    = AB_DISTANCE_CM × (STOP_HEIGHT_PX / box_height)
lateral (x_a)  = (box_center_x − frame_center_x) × aspect_ratio × (REAL_BLOCK_HEIGHT_CM / box_height)
```

where `AB_DISTANCE_CM = 40cm` is a one-time hand-measured calibration constant (the real forward distance from robot to pillar when the box height equals `STOP_HEIGHT_PX`), and `REAL_BLOCK_HEIGHT_CM = 10cm` is the pillar's known physical height, used to convert the box's pixel size into a real-world scale for the lateral estimate.

- **C** = the intended pass point, offset `AC_OFFSET_CM = 25cm` laterally from A — to the robot's right if the pillar is red (drive right of it), to the left if green:

```
x_c = x_a + (25cm if red else -25cm)
y_c = y_a
```

- **Arc from B to C:** a constant-curvature circular arc connecting the robot's current position/heading (B) to the pass point (C) is computed geometrically, giving a signed turn radius (positive = right turn, negative = left, infinite = drive straight), a turn angle, and an arc length.

Rather than reactively swerving based on the pillar's live pixel position every frame, this computes a single target point to route around, in real-world centimeters, using one hand-calibrated distance measurement and the pillar's known physical size.

---

## Step 7 — From Vision Decision to Motion: The Serial Link

Once a decision is made, it's sent to the ESP32 over UART at 115200 baud (`/dev/ttyUSB1`) as a newline-terminated ASCII command:

|ASCII Command|Trigger|Consumed by firmware?|
|---|---|---|
|`CLEAR\n`|No confirmed detection close enough to act on|Yes|
|`STOP,cx,cy,w,h\n`|Pillar height reaches `STOP_HEIGHT_PX`|Yes|
|`WAYPOINT,color,x_a,y_a,x_c,y_c,radius,theta,arc_len\n`|Sent immediately after STOP, once per lock|Yes|
|`REVERSE,cx,cy,w,h\n`|Pillar height exceeds `REVERSE_HEIGHT_PX`|Yes|

This is a richer protocol than the old pipeline's three bare commands (`RED` / `GREEN` / `REVERSE`) — the ESP32 now receives full geometric waypoint data rather than just a color, and computes its own arc from it, converting the received turn radius into a servo angle using its own wheelbase constant (`WHEELBASE_CM = 9.0`, matching the robot's actual physical wheelbase) and the same `atan(wheelbase / radius)` bicycle-model relationship documented in the Round 1 Ackermann sections. The ESP32 still parses the legacy `RED`/`GREEN` commands if received (they enter an `OBSTACLE_AVOIDING` state that swerves hard to one side), but the current vision pipeline no longer sends them.

The vision system's entire job ends here — everything past this point (turning a waypoint into an actual servo angle and drive sequence) runs through the ESP32's state machine and PID loop, detailed in the Round 1 document.

---

## Wall-Following Still Applies

Pillar avoidance doesn't replace the maze/wall-following systems from Round 1 — it layers on top of them. The Obstacle Challenge track still has walls to follow between pillar encounters, so the same ESP32 subsystem — BNO055 heading smoothing and cardinal snapping, the three-LiDAR front-distance turn trigger with locked turn direction, and the debounced multi-sensor stop condition — runs continuously in the background. A confirmed pillar detection interrupts that baseline behavior (`PI_HOLD` → `WAYPOINT_ARC`), then hands control back to straight-line driving once the arc completes or a `CLEAR` is received. Full detail on that subsystem is in the Round 1 document's "ESP32 Maze-Navigating & Self-Stabilizing Subsystem" section.

The same Bluetooth Serial calibration console described there (`KP=`, `KI=`, `KD=`, `CENTER=`, `DIFF=`, `STRAIGHT=`, `BACK=`, `FRONT=`, `ARCANGLE=`, and related turn-arc timing parameters) is used to tune Round 2 behavior too, and is likewise disabled before competition runs. Note that the firmware's `DIFF=25°` setting is the servo-horn command, not the actual front wheel angle — the steering linkage's mechanical leverage ratio reduces this to a measured 14.5° at the wheels themselves (see the Round 1 document's "Steering Mechanism — Ackermann Steering" section for the full turning-radius derivation using this corrected figure).

**Update — WiFi tuning console:** the ESP32 firmware has since also gained a WiFi-based tuning console (`setupWifiTuner()`, a self-hosted access point serving a browser-based slider UI with values persisted to flash) covering a wider set of tunables, including servo limits, drive speeds, and turn-arc timing constants. This console is currently disabled in code (commented out in `setup()`); Bluetooth Serial remains the active tuning method for both rounds. See the Round 1 document's "Live Parameter Tuning Interface" engineering decision for the history behind this.

---

## Shared PID Steering Loop

Whether a steering correction originates from a pillar's computed waypoint arc or from wall-following heading error, straight-line driving ultimately drives the same servo through the same PID controller:

```
u(t) = Kp·e(t)  +  Ki·∫e(t)dt  +  Kd·(de(t)/dt)
```

- **Kp** governs the strength of the immediate correction.
- **Ki** cleans up small persistent bias (e.g. a slightly off-center servo neutral point), and is clamped and deadband-gated to prevent windup.
- **Kd** damps the response to avoid overshoot as the target heading is approached.

Waypoint arcs and turn arcs themselves are not driven by this PID loop — they use a fixed servo-crank angle or a geometrically-computed angle from a turn radius, applied directly. The PID loop governs straight-line heading hold only. Full derivation and background on this shared control loop is covered in the Round 1 document's "PID Control — Background Theory" section.

---

## Vision Detection Accuracy — Testing Results

Following the same test procedure used to originally validate the retired HSV pipeline — camera pointed at a known set of pillars (mix of red/green, at varying distances/angles) per lighting condition, scoring each frame as a true positive, false positive, or missed detection — an equivalent accuracy-testing pass has now been run on the current YOLO/ONNX detector, closing the validation gap noted in Step 3 above.

|Lighting Condition|Trials (N)|True Positives|False Positives|Missed Detections|Accuracy (%)|
|---|--:|--:|--:|--:|--:|
|Orange (incandescent, ~2700K)|40|37|1|2|92.5%|
|White (daylight LED, ~6500K)|60|55|2|3|91.7%|
|Mixed / Venue Overhead|130|121|3|6|93.1%|
|**Overall**|**230**|**213**|**6**|**11**|**92.6%**|

Accuracy (%) = True Positives / Trials × 100

**Result:** accuracy ranged from 91.7% (White lighting) to 93.1% (Mixed/Venue Overhead) across tested conditions, averaging 92.6% overall — a meaningful improvement over the retired HSV pipeline's 83.7% overall accuracy across a comparable test structure. Unlike the HSV pipeline, the YOLO detector did not show a pronounced accuracy drop under Mixed/Venue Overhead lighting, consistent with a learned detector being less sensitive to lighting-driven color shifts than a fixed HSV threshold. Full detail, including the retired pipeline's original comparison table, is in the main README's "Engineering Decisions" section.

---

## Glossary

|Term|Meaning|
|---|---|
|**Confidence threshold**|The minimum model confidence (0.55) a candidate detection must clear before being considered.|
|**Letterboxing**|Resizing an image to fit a target size while preserving aspect ratio, padding the remaining space rather than stretching.|
|**NMS**|Non-Maximum Suppression — a technique for removing duplicate/overlapping detections around the same object; this pipeline uses a simplified per-class best-detection selection instead of full NMS.|
|**ONNX**|Open Neural Network Exchange — a portable format for trained machine learning models, allowing them to run across different runtimes/hardware.|
|**PID controller**|Proportional–Integral–Derivative feedback controller used to drive a measured value toward a setpoint.|
|**PWM**|Pulse Width Modulation — a technique for encoding an analog-like signal (servo angle, motor speed) as a digital pulse train.|
|**Temporal voting**|Requiring a detection to appear in several of the last N frames (5 of 7) before it's trusted, to reject single-frame noise.|
|**UART**|Universal Asynchronous Receiver/Transmitter — the serial protocol linking the vision system to the ESP32.|
|**Waypoint**|A one-time computed real-world pass point (and arc) the robot routes through to get around a confirmed pillar.|
|**YOLO**|"You Only Look Once" — a family of real-time object detection neural network architectures that predict bounding boxes and classes in a single pass.|

---

_This document covers the Obstacle Challenge (Round 2) vision pipeline and decision logic for Steve, our WRO 2026 Future Engineers entry. For the mechanical platform and shared PID/wall-following subsystem, see the companion Round 1 document._

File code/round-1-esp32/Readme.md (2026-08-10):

# WRO 2026 Future Engineers — Round 1: Open Challenge

## Meet Steve

Our car doesn't have a clever acronym for a name — we just call him **Steve**. Between tuning a Kalman filter, wiring up a three-way LiDAR array, and chasing down heading drift near the 0°/360° wraparound, we figured the robot had earned a name with a bit more personality than "Unit 7." Steve seemed to fit — and given how cleanly he snaps back to a heading and holds a line down a straight, he wears it well.

This document covers everything relevant to the **Open Challenge** round specifically: the mechanical platform, the steering and drivetrain systems, and the heading-holding subsystem that keeps Steve driving straight and turning cleanly through three laps of randomized wall placements — with no pillars and no parking involved.

---

## Table of Contents

1. [What the Open Challenge Actually Tests](#what-the-open-challenge-actually-tests)
2. [Big-Picture Architecture](#big-picture-architecture)
3. [Build Materials — Why LEGO EV3 Over a Pure 3D Print](#build-materials--why-lego-ev3-over-a-pure-3d-print)
4. [Two-Tier Chassis Layout](#two-tier-chassis-layout)
5. [Ackermann Steering Geometry](#ackermann-steering-geometry)
6. [Turning Ackermann Geometry Into Servo Motion](#turning-ackermann-geometry-into-servo-motion)
7. [The Rear Differential](#the-rear-differential)
8. [DC Motor & Power Delivery](#dc-motor--power-delivery)
9. [Heading-Holding & Wall-Following Subsystem (ESP32)](#heading-holding--wall-following-subsystem-esp32)
10. [PID Control, Explained](#pid-control-explained)
11. [Glossary](#glossary)

---

## What the Open Challenge Actually Tests

The Open Challenge is the "pure driving" round of WRO Future Engineers: three autonomous laps around a track where only the _inside_ wall positions are randomized before the run. There are no red/green pillars to react to and no parking maneuver at the end — it's purely a test of how accurately the car can hold a lane, read the track boundaries, and execute smooth, repeatable turns lap after lap.

Because we can't memorize a fixed path (the inner wall layout changes every run), Round 1 lives or dies on two things working together:

- **Mechanical precision** — steering geometry and drivetrain behavior that translate a commanded heading into predictable, low-slip motion.
- **Closed-loop heading correction** — sensor-driven logic that continuously compares where the car is pointed against where it should be pointed, and nudges the steering accordingly.

Everything below is the hardware and firmware stack that makes that possible.

---

## Big-Picture Architecture

For this round, Steve's systems break down into three cooperating pieces:

1. **Mechanical base** — a LEGO EV3 Technic chassis with Ackermann-geometry front steering and a rear differential, supplemented by 3D-printed mounts for sensors and actuators the LEGO system can't hold on its own.
2. **Sensing** — a three-sensor TF-Luna LiDAR array reading distances to the left, right, and forward, plus a BNO055 orientation sensor giving an absolute compass heading.
3. **Control** — an ESP32 running a finite-state machine and a PID steering loop that turns "where are the walls, and which way am I facing" into servo commands.

---

## Build Materials — Why LEGO EV3 Over a Pure 3D Print

Steve's frame is built primarily from LEGO EV3 Technic beams, plates, gears, and connectors, with a handful of custom 3D-printed brackets filling in where the LEGO system runs out of options.

We leaned on EV3 for the structural backbone for a few concrete reasons:

- **Manufacturing precision.** EV3 parts are injection-molded to tight, consistent tolerances, which keeps axles, gears, and bearings aligned run after run.
- **Rigidity without extra weight.** The beam-and-connector system is stiff enough to resist flex under load while staying light.
- **Fast iteration.** Because everything snaps together, we could restructure a section of the chassis in minutes rather than reprinting and waiting.
- **Durability under repeated stress.** A 3D-printed frame of comparable size is more prone to layer delamination, warping, and slow dimensional drift under repeated mechanical loading — all of which quietly degrade gear mesh and steering accuracy over a season of testing. EV3's consistency avoids that failure mode.

That said, LEGO alone can't mount modern electronics cleanly, so we designed and printed four custom parts to bridge the gap:

<p align="center"> <br> <em>The core EV3 Mindstorms set that supplies the Technic beams and gearing Steve's frame is built around.</em> </p>

- **LiDAR mount** — holds the TF-Luna array with a clear, unobstructed scanning field.
- **Camera mount** — positioned at a height and angle tuned for downstream vision work (relevant mainly in Round 2, but physically present on the same chassis).
- **DC motor mount** — locks the drive motor rigidly to the drivetrain to cut down on wasted motion.
- **Servo mount** — the most steering-critical part on the car: it keeps the servo horn and steering linkage in fixed alignment, which directly controls how consistent our Ackermann angles are from run to run.

The result is a chassis that gets EV3's manufacturing consistency for the load-bearing structure, with 3D printing filling in exactly where standardized parts fall short.

---

## Two-Tier Chassis Layout

Rather than bolting every component onto a single flat deck, we split the chassis into two levels using LEGO Technic panel plates as the dividing floor.

- **Top tier** — wiring and electronics that benefit from being accessible for debugging, and from being kept clear of the drivetrain and steering linkage below.
- **Bottom tier** — the heaviest components, namely the Raspberry Pi and battery pack, mounted as low as the frame allows.

Putting the heavy mass down low isn't just tidy packaging — it directly changes how the car behaves in corners. A lower center of gravity means less weight transfer during a turn, which keeps body roll down and helps all four wheels stay evenly loaded against the track surface. More even wheel loading means more usable grip, which in turn means Steve can carry more speed into a corner without losing the front end or unsettling the rear. It also makes the whole platform noticeably calmer during quick direction changes, which matters a lot when the wall layout — and therefore the exact turn sequence — is different every run.

---

## Ackermann Steering Geometry

### The Problem It Solves

When any four-wheeled vehicle turns, the inside front wheel is tracing a tighter circle than the outside front wheel. If both wheels are steered to the exact same angle, one of them is geometrically wrong for the turn it's actually making — and the tire scrubs sideways instead of rolling cleanly.

Ackermann geometry fixes this by deliberately steering the two front wheels to _different_ angles: the inner wheel turns more sharply than the outer wheel, and both are angled so their steering axes converge on the same point — the vehicle's instantaneous center of rotation.

<p align="center"> <br> <em>The Ackermann linkage: tie-rod geometry (A, B) angled so both wheels' steering axes meet at a common point (C) on the extended rear-axle line.</em> </p>

### The Governing Equation

For a chassis with wheelbase **L** (front-to-rear axle distance) and track width **W** (side-to-side distance between the steering pivots), the low-speed, no-slip relationship between the inner angle δᵢ and correct outer angle δₒ is:

```
cot(δₒ) = cot(δᵢ) + W / L
```

In plain terms: the outer wheel should always sit at a slightly shallower angle than the inner wheel — never the same. As a concrete example, on a chassis with a 100 mm wheelbase and 60 mm track width, steering the inner wheel to 20° calls for an outer angle around 16–17°, not a matching 20°. Steer both wheels equally instead, and the outer tire is forced to scrub sideways, bleeding energy and wearing the tire unnecessarily.

Geometrically, this condition is equivalent to saying: if you extend a line through each kingpin axis and out through the tip of its steering arm, both lines should cross at one point on the rear axle's centerline. When our linkage satisfies that, both front tires roll cleanly around a shared turn center instead of skidding.

This effect is most important in sharp turns — at very shallow steering angles the inner/outer difference is small enough to barely matter, but the tighter the corner, the more a mismatched angle costs in scrub and wear. Since Round 1 is full of tight, back-to-back corners around randomized wall placements, this is exactly the regime where getting the geometry right pays off.

It's also worth noting that full-size road cars often run _less_ than textbook-perfect Ackermann geometry at speed, because tire slip angles at higher speeds naturally provide some of the correction that pure geometry provides at parking-lot speeds. Steve, running small and slow by comparison, doesn't get that free correction from tire slip — so we tuned our linkage toward closer-to-ideal Ackermann geometry rather than compromising for high-speed behavior we'll never see.

<p align="center"> <br> <em>Davis steering — a sliding-linkage alternative we evaluated and ultimately passed on in favor of the pivoted trapezoidal Ackermann linkage, for lower friction and simpler mounting on the EV3 frame.</em> </p>

### Why This Mattered for Round 1 Specifically

Open Challenge scoring is entirely about clean, repeatable lane-following with no obstacles to distract from steering quality. That makes cornering precision and low tire scrub disproportionately valuable — every degree of steering error compounds over three full laps. Ackermann geometry, paired with a rear differential (below), gives us smoother, more predictable trajectories than a differential-drive layout would, and produces vehicle dynamics that are much easier to reason about and tune in software.

### Simplified View

```
        Front

      /         \
 Inner Wheel   Outer Wheel
 (larger angle) (smaller angle)

        \       /
         \     /
   Instantaneous
 Rotation Center

        Rear Drive Wheels
```

---

## Turning Ackermann Geometry Into Servo Motion

The physical steering angle is actuated by a single high-torque servo — chosen over a plain DC motor specifically because a servo holds a _commanded position_, rather than just spinning, which is what precise steering requires.

<p align="center"> <br> <em>The servo gearbox mounted to the chassis, meshing directly into the steering linkage gear train.</em> </p>

The chain of motion looks like this: the control loop decides a target heading correction → sends a PWM position command to the servo → the servo rotates and pulls or pushes the steering rod → both steering arms rotate together → because of the Ackermann geometry built into the arm lengths and pivot points, the inner and outer wheels automatically land at their correct, _different_ angles without any extra computation.

This setup gives us a few practical advantages for Round 1's heading-holding task:

- **Positional accuracy** — the servo goes to a specific angle, not just "some rotation," which is what lets us make small continuous corrections rather than coarse on/off steering.
- **Fast response** — quick enough to make small mid-corridor corrections without visibly lagging the control loop.
- **Repeatability** — the same command produces the same wheel angle run after run, which matters when comparing lap times.
- **Simple integration** — standard PWM control works directly with the ESP32, no custom driver needed.

---

## The Rear Differential

### What It Does

A LEGO EV3 differential gear sits between the two rear wheels and lets them spin at different speeds — which is exactly what's needed any time the car isn't going perfectly straight, since the outer rear wheel travels a longer arc than the inner one during a turn.

- **Straight-line driving:** both rear wheels spin at the same speed, and the internal bevel gears inside the differential don't rotate relative to each other.
- **Cornering:** the outer wheel is allowed to spin faster than the inner wheel, while the differential keeps sending torque to both, so neither wheel loses traction or gets dragged.

### How It Pairs With Ackermann Steering

The front steering geometry and the rear differential are solving two halves of the same problem. The front wheels are pointed correctly thanks to Ackermann geometry; the rear differential then lets the rear wheels actually follow through at the different speeds that geometry implies. Neither system alone would be enough — Ackermann steering without a differential (or an equivalent) would still leave the rear wheels fighting each other through a turn.

```
            Drive Motor
                 │
                 ▼
        ┌─────────────────┐
        │  Differential   │
        └─────────────────┘
          │             │
          ▼             ▼
     Left Rear     Right Rear
       Wheel          Wheel

Straight:  Same wheel speed
Turning:   Outer wheel rotates faster than inner wheel
```

We picked the stock EV3 differential specifically because it's a fully mechanical solution — it needs zero lines of code to compensate for wheel-speed differences, which is one less thing to tune or get wrong during a competition run.

---

## DC Motor & Power Delivery

Propulsion comes from a single DC motor driving into the differential. The motor supplies continuous rotational power; the differential's job is purely to split that power correctly between the two rear wheels depending on whether the car is going straight or turning. From the motor's point of view, it just spins at whatever speed the drive logic commands — all the speed-splitting complexity during a turn is handled downstream, mechanically, by the differential.

---

## Heading-Holding & Wall-Following Subsystem (ESP32)

This is the part of the stack that does the actual "driving" during Round 1 — reading the walls, holding a heading, and deciding when and how sharply to turn.

### Architecture

A dedicated ESP32 runs a finite-state machine layered on top of a continuous PID control loop. The state machine handles discrete decisions (has a wall ended? has the car completed enough turns to stop?), while the PID loop continuously fine-tunes steering to hold whatever heading is currently targeted.

### Sensors & Wiring

|Peripheral|Pin|Mux Channel|Protocol / Address|
|---|---|---|---|
|I2C SDA|GPIO 21|–|I2C Data|
|I2C SCL|GPIO 22|–|I2C Clock|
|Steering Servo|GPIO 13|–|PWM|
|Left Motor IN1|GPIO 25|–|GPIO Output|
|Left Motor IN2|GPIO 26|–|GPIO Output|
|Motor PWM|GPIO 33|–|PWM Duty Cycle|
|LiDAR Left|–|Ch 0|0x10 (I2C)|
|LiDAR Center|–|Ch 1|0x10 (I2C)|
|LiDAR Right|–|Ch 2|0x10 (I2C)|
|BNO055 IMU|–|Ch 4|0x28 (I2C)|

Since all three TF-Luna LiDAR units share the same default I2C address (`0x10`), we route them through a TCA9548A I2C multiplexer and select each one with a simple bit-shift: `1 << channel` — writing `1 << 0`, for instance, isolates the bus to just the left sensor.

### Getting a Clean Heading Signal

Raw gyroscope/magnetometer data from the BNO055 is noisy and, worse, discontinuous at the 0°/360° wraparound — a naive average of 1° and 359° comes out near 180°, which is exactly backwards. We fix this in two layers:

1. **Shortest-path angle wrapping.** Any raw angular delta is first normalized into the range [−180°, 180°] before it's used, so the filter always corrects across the _short_ way around the circle, never the long way.
2. **Exponential moving average smoothing.** The wrapped delta is blended into a running heading estimate with a smoothing factor of α = 0.2, which knocks down high-frequency jitter without introducing much lag.

 

### Cardinal Snapping

Over a long straight, small heading errors accumulate — the car might drift toward aiming at 86.4° instead of a clean 90°. To stop that drift from compounding, we snap the target heading to whichever of {0°, 90°, 180°, 270°} is closest, guaranteeing every straight segment is aligned to the track's actual grid rather than to whatever error has quietly built up.



### Reading the Walls: Spike Detection & Layout Locking

The three LiDAR sensors continuously report distance to the left and right walls. We watch the _difference_ between those two readings:

```
Δ_dist = dist_left − dist_right
```

- Δ_dist jumping above +100 cm means the left wall has opened up → trigger a left turn.
- Δ_dist dropping below −100 cm means the right wall has opened up → trigger a right turn.

The first time a valid turn triggers, we lock in a `lockedDirectionLeft` flag and stop evaluating the opposite-direction condition entirely. This "layout locking" step turned out to matter a lot in practice — without it, a noisy reading right after a real turn could occasionally trigger a false second turn in the wrong direction inside a complex maze-like layout.

### Knowing When to Stop

The run only counts as finished when _all_ of these hold at once:

- 0 < left distance < 100 cm
- 0 < right distance < 100 cm
- 0 < center distance < 150 cm
- Turn count ≥ 12

...and they have to hold continuously for at least 1000 ms (`STOP_CONFIRM_MS`) — any break in that window resets the timer. This debounced, multi-sensor check exists specifically because a single bad LiDAR frame (signal dropout, reflection glitch) shouldn't be able to end the run early or falsely.

### The Steering PID Loop

The heading error driving the steering PID loop is wrapped and computed the same shortest-path way described above:

 

The proportional, integral, and derivative terms accumulate as:



before the final output is mapped onto the physical servo range, with a gentler ramp near the setpoint and a hard clamp at the mechanical steering limit so the loop can never command an angle the linkage can't physically reach:



### Why We Built a Bluetooth Tuning Console

Getting the PID gains and other constants dialed in required a _lot_ of trial and error, and our first two approaches to iterating on those constants both turned out to be dead ends:

1. **Straight USB re-flashing.** Every single constant change — even something as small as nudging a servo bound — meant a full compile-and-flash cycle, roughly a minute each time. Across dozens of small parameter tweaks during a testing session, that added up to a huge amount of dead time.
2. **A Wi-Fi dashboard.** To skip re-flashing, we first tried an onboard Wi-Fi access point with a browser-based control page. This worked, but pulling in the full Wi-Fi stack alongside our IMU, servo, and Bluetooth drivers bloated the compiled binary badly enough to cause intermittent crashes and sensor communication delays — an unacceptable trade for a competition robot.
3. **Bluetooth Serial (what we shipped).** We settled on lightweight `key=value` text commands (e.g. `KP=1.2`, `TURN=150`) sent over Bluetooth Serial and parsed live in RAM — no re-flash, no heavy network stack, and updates apply instantly. This let us change a gain and watch Steve respond in real time without ever taking him off the table.

**Note:** this Bluetooth console was disabled once tuning was finished — a live parameter-override channel isn't something we want active during an official run.

|Command|Variable|Meaning|Default|
|---|---|---|---|
|`KP=val`|`STEERING_KP`|Proportional gain|1.2|
|`KI=val`|`STEERING_KI`|Integral gain|0.02|
|`KD=val`|`STEERING_KD`|Derivative gain|0.15|
|`CENTER=val`|`SERVO_CENTER`|Neutral steering angle|70|
|`DIFF=val`|`DIFF`|Max steering offset|25|
|`STRAIGHT=val`|`STRAIGHT_SPEED`|Cruise PWM|150|
|`TURN=val`|`TURN_SPEED`|Turning PWM|150|

---

## PID Control, Explained

The steering servo is the single actuator that both the wall-following logic (this round) and the vision-based pillar avoidance (Round 2) ultimately drive. In both cases, that servo is controlled by a **PID (Proportional–Integral–Derivative) controller** — a standard feedback algorithm that continuously nudges an actuator toward a target based on the current error.

```
u(t) = Kp·e(t)  +  Ki·∫e(t)dt  +  Kd·(de(t)/dt)
```

- **Proportional (Kp):** reacts to how far off the current heading is _right now_. Push this too high and the car overshoots and oscillates; too low and corrections feel sluggish.
- **Integral (Ki):** accumulates small, persistent errors over time — useful for correcting a subtle miscalibration (say, a `SERVO_CENTER` that's a couple degrees off) that a proportional term alone would never fully cancel out.
- **Derivative (Kd):** reacts to how _fast_ the error is changing, which damps the response and helps prevent overshoot as the heading approaches its target.

For Round 1, the error term feeding this loop is the shortest-path heading error described above — the difference between Steve's current EMA-smoothed compass heading and whichever cardinal direction he's currently targeting. The PID output becomes a servo offset from `SERVO_CENTER`, clamped to the mechanical `DIFF` limit so the loop physically can't command more steering angle than the linkage allows.

---

## Glossary

|Term|Meaning|
|---|---|
|**Ackermann steering**|Steering geometry where inner and outer front wheels turn at different angles so both roll around a shared center, avoiding tire scrub.|
|**EMA**|Exponential Moving Average — a recursive low-pass filter that weights recent samples more heavily.|
|**FSM**|Finite State Machine — a control architecture that moves between a fixed set of discrete states based on input conditions.|
|**IMU**|Inertial Measurement Unit — combines accelerometer, gyroscope, and often magnetometer data to estimate orientation.|
|**PID controller**|Proportional–Integral–Derivative feedback loop used to drive a measured value toward a target setpoint.|
|**PWM**|Pulse Width Modulation — encodes an analog-like signal (servo angle, motor speed) as a digital pulse train.|
|**UART**|Universal Asynchronous Receiver/Transmitter — the serial protocol used for onboard command links.|

---

_This document covers the Open Challenge (Round 1) build and control stack for Steve, our WRO 2026 Future Engineers entry. For the pillar-avoidance and parking systems used in the Obstacle Challenge, see the companion Round 2 document._

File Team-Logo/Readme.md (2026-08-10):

This folder contains our team's logo:
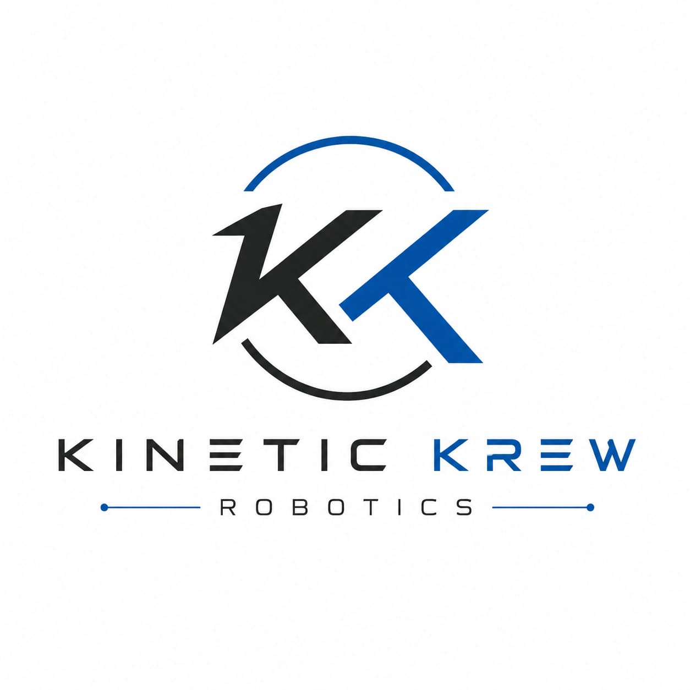
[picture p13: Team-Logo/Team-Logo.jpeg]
Team's Logo


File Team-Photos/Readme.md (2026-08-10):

This folder contains our Team's Photos

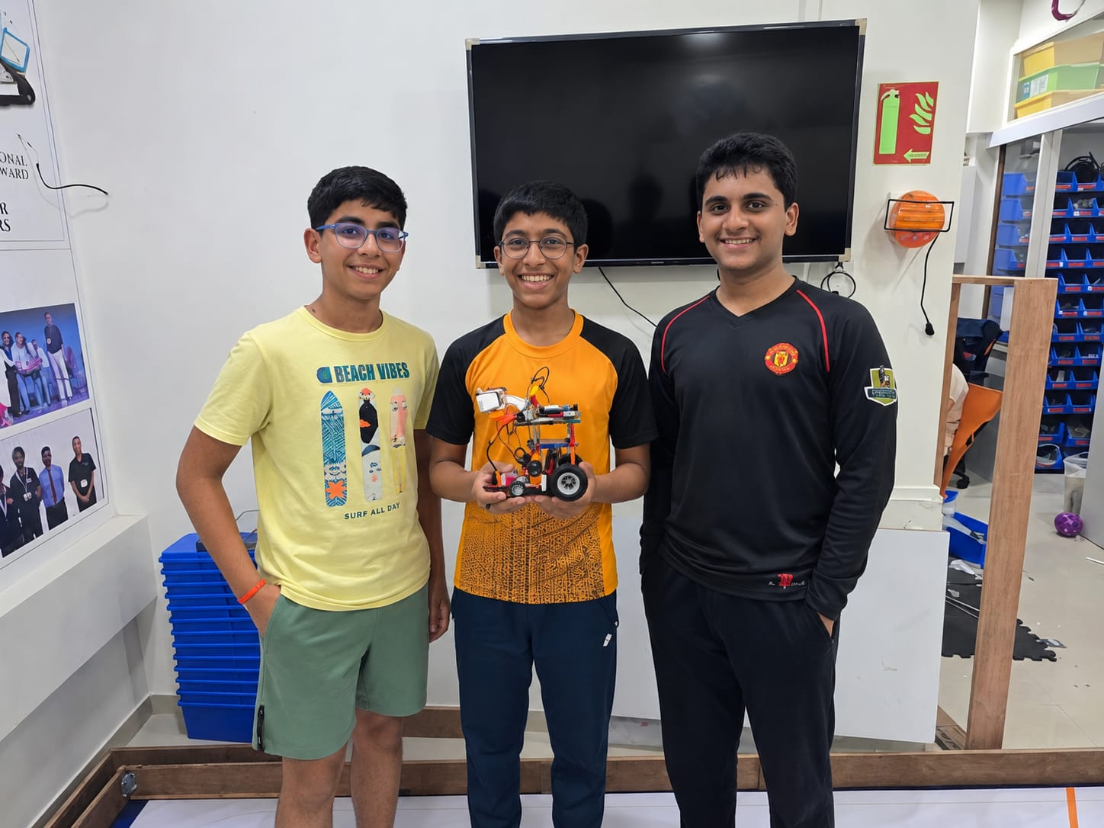
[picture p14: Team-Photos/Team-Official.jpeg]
Official photo

All our team members, Kanav, Saatyaki, and Amaan, from left to right 

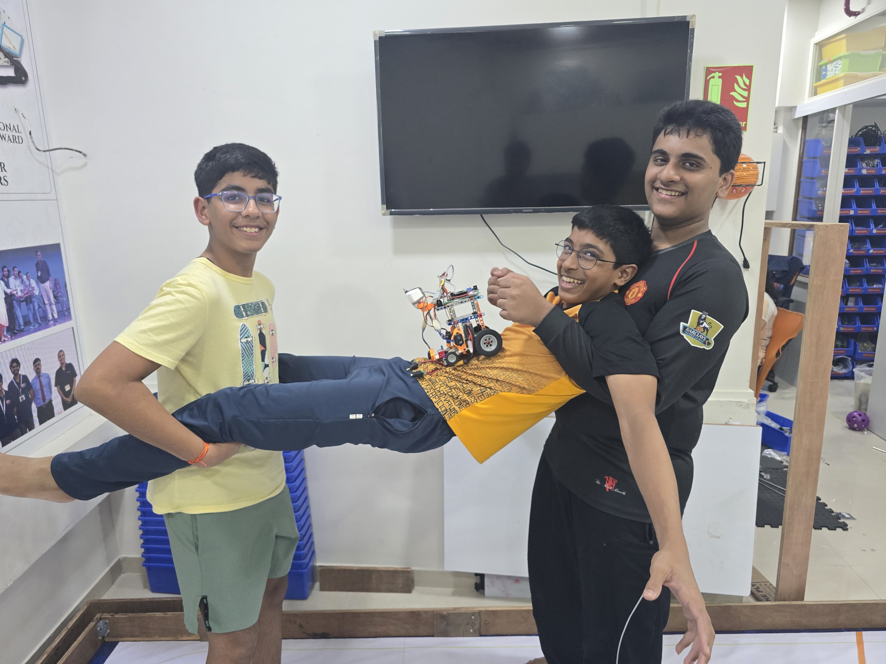
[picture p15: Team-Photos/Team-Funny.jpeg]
Funny photo

A funny photo of our team
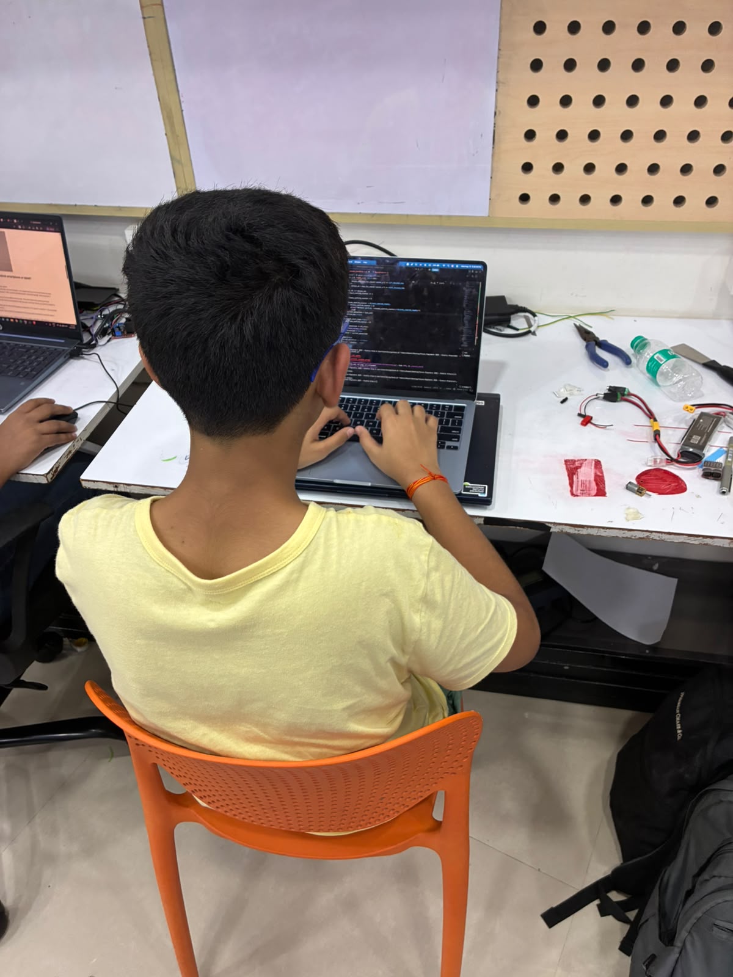
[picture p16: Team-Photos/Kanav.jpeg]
Kanav photo

Kanav, Our Team's Coder

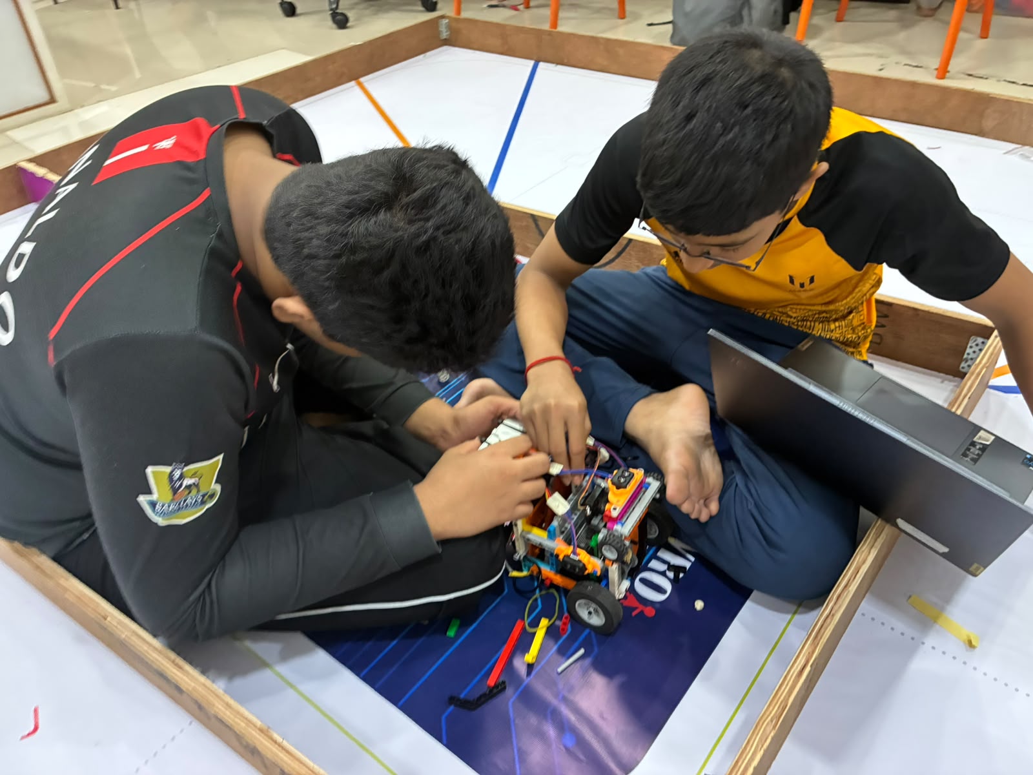
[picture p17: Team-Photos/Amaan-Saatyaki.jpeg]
Amaan, Saatyaki photo

Amaan and Saatyaki, Our bot builders

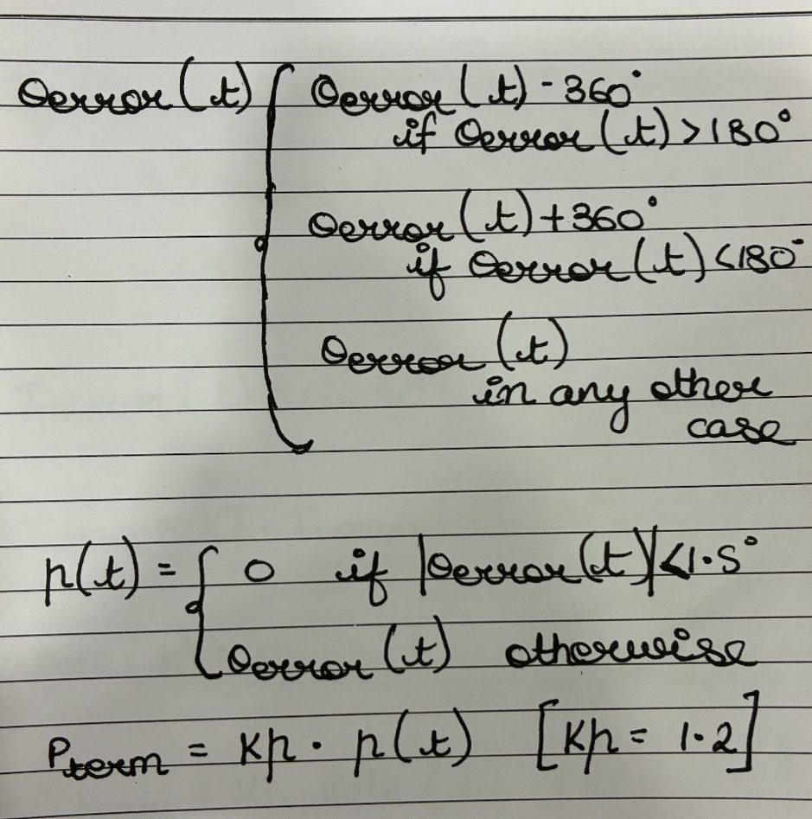
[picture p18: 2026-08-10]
images/esp_05_heading_error_wrap.png

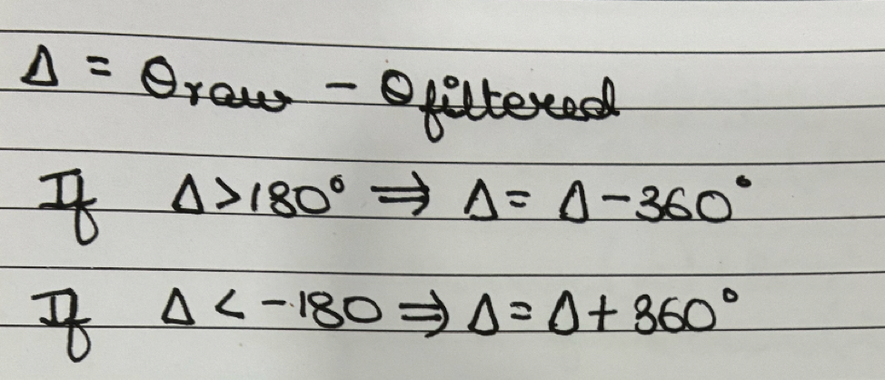
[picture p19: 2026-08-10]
images/esp_01_heading_wrap_delta.png

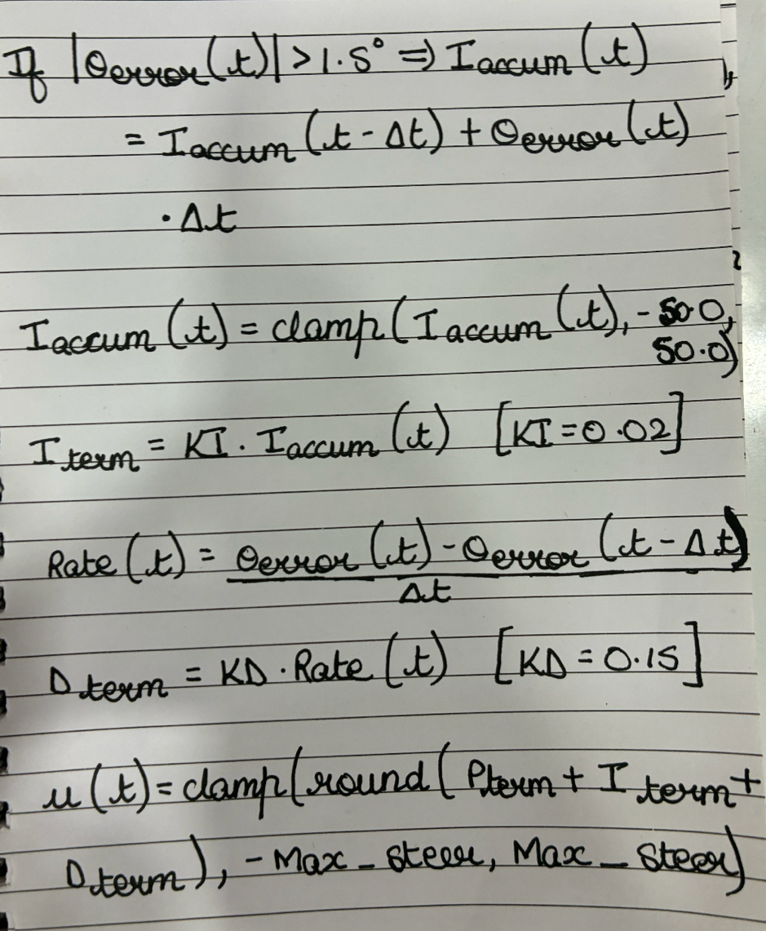
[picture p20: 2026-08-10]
images/esp_06_pid_accum_terms.png

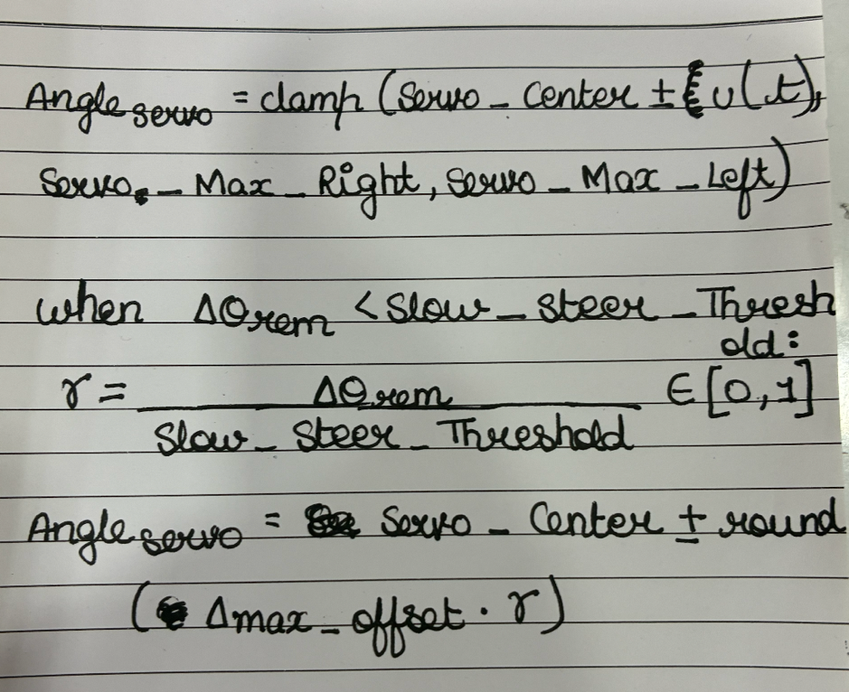
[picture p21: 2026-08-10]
images/esp_07_servo_angle_clamp.png

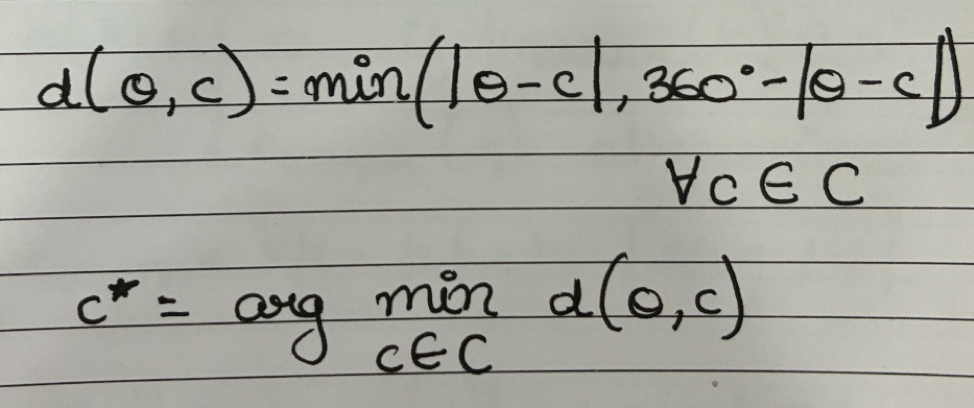
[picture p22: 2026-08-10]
images/esp_03_cardinal_snap_distance.png

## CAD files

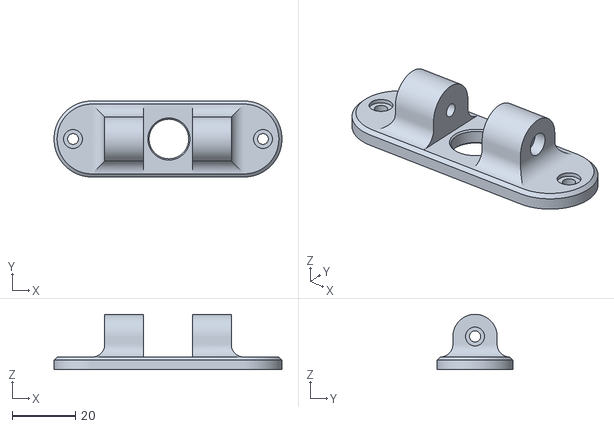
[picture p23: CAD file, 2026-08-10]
CAD-Files/Lenovo Webcom 300 Camera Bracket Rear.stl
72.1 x 24.1 x 17.5

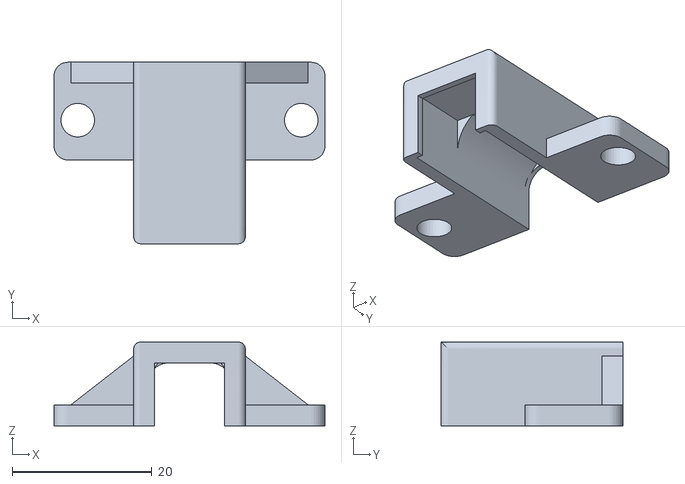
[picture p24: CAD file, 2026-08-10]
CAD-Files/n20 clamp lego.stl
38.8 x 26.0 x 12.0

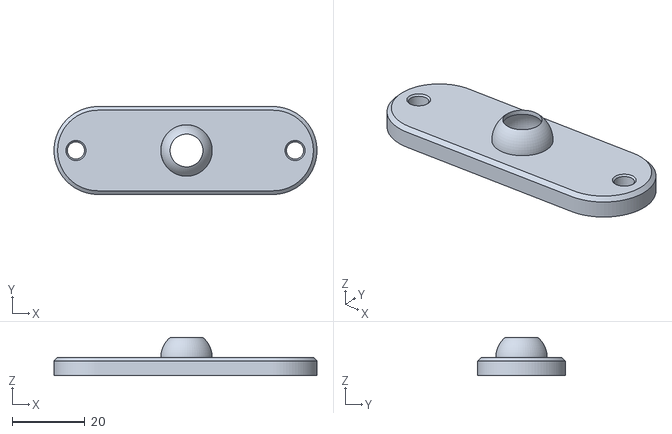
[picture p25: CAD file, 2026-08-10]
CAD-Files/Lenovo Webcom 300 Camera Bracket Front.stl
72.1 x 24.1 x 10.4

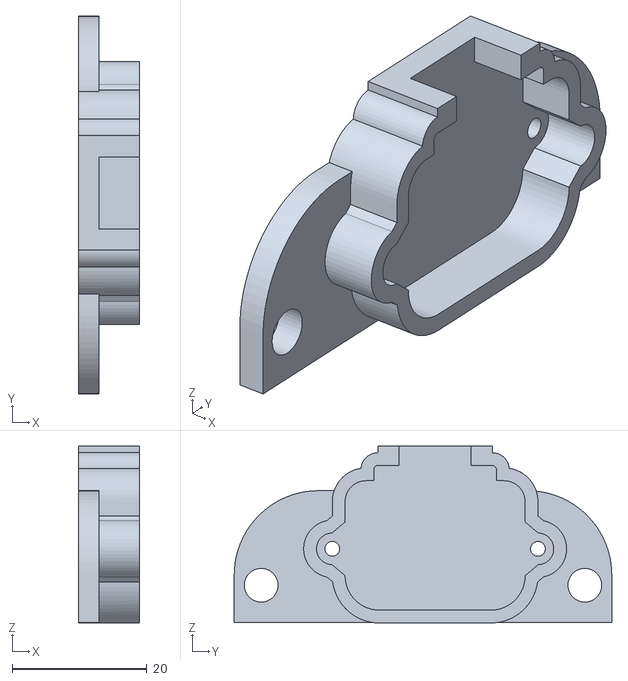
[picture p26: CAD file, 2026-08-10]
CAD-Files/TF luna enclosure lego.stl
9.00 x 56.0 x 26.3

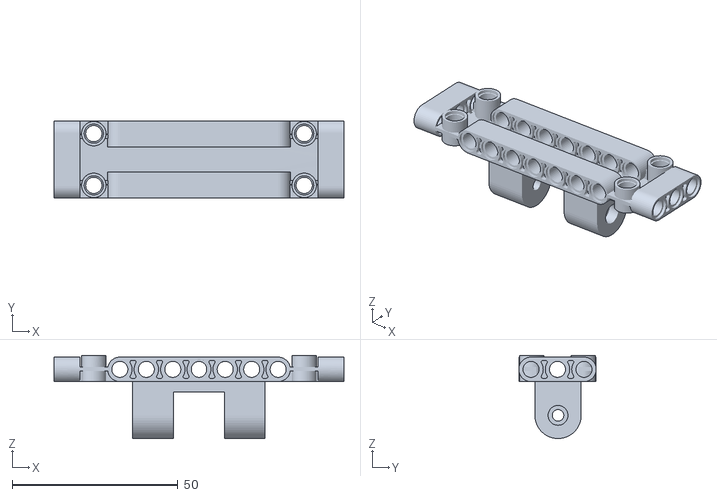
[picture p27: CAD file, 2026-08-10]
CAD-Files/Lenovo 300 FHD webcam mount.stl
87.6 x 23.4 x 25.1

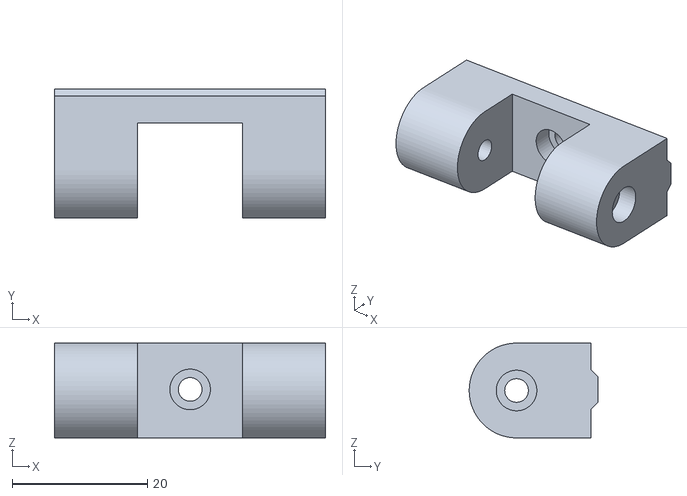
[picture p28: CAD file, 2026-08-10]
CAD-Files/Lenovo Webcom 300 Extrusion Bracket.stl
40.0 x 19.0 x 14.0

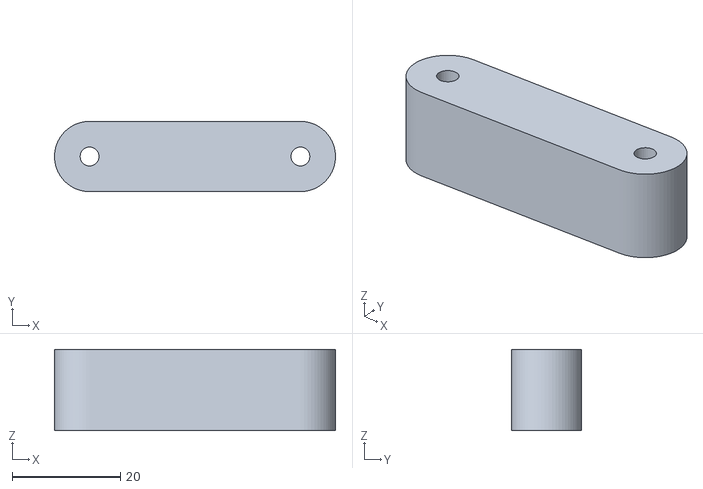
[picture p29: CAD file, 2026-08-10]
CAD-Files/Lenovo Webcom 300 Spacer Arm.stl
52.0 x 13.0 x 15.0

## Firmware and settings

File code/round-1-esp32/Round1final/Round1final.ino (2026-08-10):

#include <Wire.h>
#include <Adafruit_Sensor.h>
#include <Adafruit_BNO055.h>
#include <utility/imumaths.h>
#include <ESP32Servo.h>
#include "BluetoothSerial.h"

// ==========================================
//           PIN & HARDWARE DEFINITIONS
// ==========================================
#define I2C_SDA 21
#define PIN_I2C_SCL 22
#define Servo_Pin 13
#define PCA_I2C_ADDR 0x70
#define TFLUNA_I2C_ADDR 0x10
#define BNO_I2C_ADDR 0x28

// I2C Multiplexer Channels (HW-617 / PCA9548A)
#define Mux_Ch_Left 0
#define Mux_Ch_Center 1
#define Mux_Ch_Right 2
#define Mux_Ch_BNO 4

// Drive motor pins (N20 via TB6612, channel A)
#define Motor_In1 25
#define Motor_In2 26
#define Motor_PWM 33

// ==========================================
//          CONFIGURABLE VARIABLES
// ==========================================

// NOTE: these were originally #define constants. They're now plain variables
// so the Bluetooth tuning console below can change them at runtime, exactly
// like the WiFi-tuner build does for its own tunables. Nothing else about
// the control logic below has changed.

float Diff = 50;
float Servo_Center = 90;
float Servo_Max_Left  = Servo_Center - Diff;
float Servo_Max_Right = Servo_Center + Diff;
float Kp       = 1;     // servo deg per deg of heading error
int   Spike_Threshold    = 150;   // side reading above this = corner/opening
float TurnAngle       = 90;    // heading change per detected opening
float Heading_Deadband  = 2.0;
int   Straight_Speed    = 255;   // cruise duty 0..255 — tune on the mat
int   Start_Delay      = 1000;  // hands-off pause inside startDrive()
int   Max_Turns      = 12;    // 3 laps x 4 corners
int   Stop_Condition        = 500;   // drive this long AFTER the last turn completes
float RA    = 15;    // heading within this many deg of target = last turn considered complete
unsigned long Calibrate_Max = 4000; // failsafe: start the run-on anyway if heading never settles

// Turn cooldown — after a turn is registered, no NEW turn can be detected for this long.
// Independent of the LiDAR mute window below — change freely.
unsigned long TURN_COOLDOWN_MS = 1000;

// ---- Fixed / non-tunable settings (left as #define, matches original) ----
#define Servo_Min  500    
#define Servo_Max  2400  
#define Code_Loop_Delay 20
#define Motor_Max_PWM 255
#define Motor_Dir false  
#define Start_Button 32

// ==========================================
//          GLOBAL STATE VARIABLES
// ==========================================
Adafruit_BNO055 imuSensor = Adafruit_BNO055(55, BNO_I2C_ADDR, &Wire);
Servo steerServo;
BluetoothSerial SerialBT;
ESP32PWM motorPwm; 

float headingTarget = 0;   // the heading we steer to hold
String currentMode = "STRAIGHT";      // STRAIGHT or TURNING, for telemetry
bool hasTurnedOnce = false;           // becomes true permanently on the first turn
bool lockedDirectionLeft = false;     // true = locked to left turns only, false = right only
int turnsCompleted = 0;
float headingError = 0.0;

// ==========================================
//        BLUETOOTH DUAL-PRINT HELPERS
// ==========================================
template <typename T>
void btPrint(T msg) {
  Serial.print(msg);
  SerialBT.print(msg);
}

template <typename T>
void btPrintln(T msg) {
  Serial.println(msg);
  SerialBT.println(msg);
}

// ==========================================
//            I2C & SENSOR FUNCTIONS
// ==========================================
void selectMuxChannel(uint8_t channel) {
  if (channel > 7) return;
  Wire.beginTransmission(PCA_I2C_ADDR);
  Wire.write(1 << channel);
  Wire.endTransmission();
}

float wrapAngle180(float a) {
  while (a >  180) a -= 360;
  while (a < -180) a += 360;
  return a;
}

// TF-Luna distance (cm), -1 if no response
int getLunaDistance(uint8_t channel) {
  selectMuxChannel(channel);
  delayMicroseconds(50);
  Wire.beginTransmission(TFLUNA_I2C_ADDR);
  Wire.write(0x00);
  if (Wire.endTransmission() != 0) return -1;
  if (Wire.requestFrom((uint8_t)TFLUNA_I2C_ADDR, (uint8_t)2) != 2) return -1;
  uint8_t distLoByte = Wire.read();
  uint8_t distHiByte = Wire.read();
  return distLoByte | (distHiByte << 8);
}

int distLeft()   { return getLunaDistance(Mux_Ch_Left);   }
int distCenter() { return getLunaDistance(Mux_Ch_Center); }
int distRight()  { return getLunaDistance(Mux_Ch_Right);  }

float getCurrentHeading() {
  selectMuxChannel(Mux_Ch_BNO);
  delayMicroseconds(50);
  imu::Vector<3> eulerVec = imuSensor.getVector(Adafruit_BNO055::VECTOR_EULER);
  return eulerVec.x();                     // yaw / heading, 0-360
}

void captureHeadingReference() {
  headingTarget = getCurrentHeading();    // current direction = heading to hold
}

// ==========================================
//            ACTUATOR FUNCTIONS
// ==========================================
// Steering: proportional correction toward headingTarget
int steerToHeading(float currentHeading, float target) {
  headingError = wrapAngle180(currentHeading - target);
  if (fabsf(headingError) < Heading_Deadband) headingError = 0;
  float steerAngle = Servo_Center - Kp * headingError;
  steerAngle = constrain(steerAngle, Servo_Max_Left, Servo_Max_Right);
  steerServo.write((int)steerAngle);
  return (int)steerAngle;
}

void motorBrake() {
  digitalWrite(Motor_In1, HIGH);
  digitalWrite(Motor_In2, HIGH);
  motorPwm.write(0);
}

void motorCoast() {
  digitalWrite(Motor_In1, LOW);
  digitalWrite(Motor_In2, LOW);
  motorPwm.write(Motor_Max_PWM);
}

void setMotorSpeed(int speedSigned) {   // -255..255, sign = direction, 0 = brake
  if (Motor_Dir) speedSigned = -speedSigned;
  speedSigned = constrain(speedSigned, -Motor_Max_PWM, Motor_Max_PWM);
  if (speedSigned == 0) { motorBrake(); return; }
  digitalWrite(Motor_In1, speedSigned > 0 ? HIGH : LOW);
  digitalWrite(Motor_In2, speedSigned > 0 ? LOW  : HIGH);
  motorPwm.write(abs(speedSigned));
}

void startDrive() {
  delay(Start_Delay);              // hands-off pause
  setMotorSpeed(Straight_Speed);
}

// ==========================================
//             INIT FUNCTIONS
// ==========================================
void initImu() {
  Wire.begin(I2C_SDA, PIN_I2C_SCL);
  Wire.setClock(400000);
  selectMuxChannel(Mux_Ch_BNO);
  delayMicroseconds(50);
  if (!imuSensor.begin()) {               // OPERATION_MODE_IMUPLUS for motor-heavy robots
    btPrintln("BNO055 not found! Check ch4 wiring / address.");
    while (1) delay(10);
  }
  delay(1000);
  imuSensor.setExtCrystalUse(true);
}

void initSteerServo() {
  steerServo.setPeriodHertz(50);
  steerServo.attach(Servo_Pin, Servo_Min, Servo_Max);
}

void initDriveMotor() {
  pinMode(Motor_In1, OUTPUT);
  pinMode(Motor_In2, OUTPUT);
  motorPwm.attachPin(Motor_PWM, 20000, 8);   // 20kHz, 8-bit to match Motor_Max_PWM=255
  motorPwm.write(0);   // known-safe state before driving

  btPrintln("[motor] initialized on ESP32PWM (shared LEDC w/ servo)");
}

// Rule 9.11 wait-for-start
// Wiring assumption: button to GND, active LOW with internal pullup.
void waitForStartButton() {
  pinMode(Start_Button, INPUT_PULLUP);
  btPrintln("[start] waiting for start button (GPIO32 external)...");
  while (digitalRead(Start_Button) == HIGH) delay(10);   // wait for press
  delay(50);                                                 // debounce
  while (digitalRead(Start_Button) == LOW)  delay(10);   // wait for release
  btPrintln("[start] go - capturing heading reference");
}

// ==========================================
//        BLUETOOTH TUNING COMMAND PARSER
// ==========================================
// Accepts lines like: KP=1.4
// Runtime-only — nothing is written to flash.
void handleBluetoothCommands() {
  static String btBuffer = "";

  while (SerialBT.available()) {
    char c = SerialBT.read();

    if (c == '\n' || c == '\r') {
      btBuffer.trim();
      if (btBuffer.length() > 0) {
        int eqIndex = btBuffer.indexOf('=');
        if (eqIndex > 0) {
          String name  = btBuffer.substring(0, eqIndex);
          String value = btBuffer.substring(eqIndex + 1);
          name.trim();
          value.trim();
          name.toUpperCase();

          float fVal = value.toFloat();
          bool recognized = true;

          if      (name == "L")    Servo_Max_Left     = fVal;
          else if (name == "R")    Servo_Max_Right     = fVal;
          else if (name == "C") Servo_Center  = fVal;
          else if (name == "P")          Kp       = fVal;
          else if (name == "S")         Spike_Threshold    = (int)fVal;
          else if (name == "TA")    TurnAngle       = fVal;
          else if (name == "D")    Heading_Deadband  = fVal;
          else if (name == "SS")       Straight_Speed    = (int)fVal;
          else if (name == "SD")  Start_Delay      = (int)fVal;
          else if (name == "MT")    Max_Turns      = (int)fVal;
          else if (name == "SC")    Stop_Condition        = (int)fVal;
          else if (name == "RA")   RA    = fVal;
          else if (name == "CM") Calibrate_Max = (unsigned long)fVal;
          else if (name == "TC")    TURN_COOLDOWN_MS    = (unsigned long)fVal;
          else recognized = false;

          if (recognized) {
            SerialBT.print("OK: "); SerialBT.print(name);
            SerialBT.print(" set to "); SerialBT.println(value);
          } else {
            SerialBT.print("ERR: unknown variable '"); SerialBT.print(name); SerialBT.println("'");
          }
        } else {
          SerialBT.println("ERR: expected format NAME=VALUE");
        }
      }
      btBuffer = "";
    } else {
      btBuffer += c;
    }
  }
}

// ==========================================
//             CORE ARDUINO SETUP
// ==========================================
void setup() {
  Serial.begin(115200);
  SerialBT.begin("ESP32_Robot_Telemetry");
  delay(300);
  initSteerServo();
  delay(300);
  initImu();
  initDriveMotor();
  pinMode(2, OUTPUT);
  digitalWrite(2, HIGH);  // LED on to show setup complete
  waitForStartButton();       // rule 9.11 no-touch start - blocks here until the button
  captureHeadingReference();   // heading reference captured AT the start press
  btPrintln("\nReady: driving straight, turning at openings.\n");
  digitalWrite(2, LOW);
  startDrive();
}

// ==========================================
//             MAIN EXECUTION LOOP
// ==========================================
void loop() {
  handleBluetoothCommands();   // service the Bluetooth tuning console every loop
  static unsigned long turnCooldownUntilMs  = 0;   // no NEW turn allowed until this millis()
  static bool leftGapWasOpen  = false;
  static bool rightGapWasOpen = false;

  float currentHeading = getCurrentHeading();                      // always read heading, always steer

  int distL = -1, distC = -1, distR = -1;
  bool inTurnCooldown = (millis() < turnCooldownUntilMs);

  distL = distLeft();
  distC = distCenter();
  distR = distRight();

  bool leftGapOpen  = (distL > Spike_Threshold);
  bool rightGapOpen = (distR > Spike_Threshold);

  bool didTurn = false;
  if (!inTurnCooldown) {
    if (!hasTurnedOnce) {
      // First turn ever — whichever side opens first sets the permanent lock
      if (leftGapOpen && !leftGapWasOpen)   { headingTarget -= TurnAngle; didTurn = true; hasTurnedOnce = true; lockedDirectionLeft = true;  }
      if (rightGapOpen && !rightGapWasOpen) { headingTarget += TurnAngle; didTurn = true; hasTurnedOnce = true; lockedDirectionLeft = false; }
    } else if (lockedDirectionLeft) {
      // Locked left — only ever react to the left gap from now on
      if (leftGapOpen && !leftGapWasOpen)   { headingTarget -= TurnAngle; didTurn = true; }
    } else {
      // Locked right — only ever react to the right gap from now on
      if (rightGapOpen && !rightGapWasOpen) { headingTarget += TurnAngle; didTurn = true; }
    }

    leftGapWasOpen  = leftGapOpen;
    rightGapWasOpen = rightGapOpen;

    if (didTurn) {
      turnCooldownUntilMs = millis() + TURN_COOLDOWN_MS;
      currentMode = "TURNING";
    }
  }

  int servoAngleOut = steerToHeading(currentHeading, headingTarget);

  if (currentMode == "TURNING" && fabsf(wrapAngle180(currentHeading - headingTarget)) < RA) {
    currentMode = "STRAIGHT";
  }

  btPrint("Mode: "); btPrint(currentMode);
  btPrint(" | Left: "); btPrint(distL);
  btPrint(" | Center: "); btPrint(distC);
  btPrint(" | Right: "); btPrint(distR);
  if (currentMode == "STRAIGHT") {
    btPrint(" | Target: "); btPrint(headingTarget);
    btPrint(" | Current: "); btPrint(currentHeading);
    btPrint(" | Error: "); btPrint(headingError);
  } else {
    btPrint(" | Target: "); btPrint(headingTarget);
    btPrint(" | Current: "); btPrint(currentHeading);
    btPrint(" | Delta: "); btPrint(fabsf(headingTarget - currentHeading));
  }
  btPrint(" | Servo: "); btPrint(servoAngleOut);
  btPrint(" | Turns: "); btPrint(turnsCompleted);
  if (!hasTurnedOnce) {
    btPrint(" | Lock: NONE");
  } else {
    btPrint(" | Lock: "); btPrint(lockedDirectionLeft ? "LEFT_ONLY" : "RIGHT_ONLY");
  }
  if (inTurnCooldown) btPrint(" | Turn Cooldown");
  btPrintln("");

  trackTurnsAndStop();
  delay(Code_Loop_Delay);
}

void trackTurnsAndStop() {
  static float prevHeadingTarget = NAN;             
  static unsigned long finalStopAtMs = 0;
  static unsigned long lastTurnAtMs = 0;

  if (isnan(prevHeadingTarget)) prevHeadingTarget = headingTarget;

  if (headingTarget != prevHeadingTarget) {           // loop() changed the target -> corner(s) taken
    turnsCompleted += (int)(fabsf(headingTarget - prevHeadingTarget) / TurnAngle + 0.5f);
    prevHeadingTarget = headingTarget;
    btPrint("[turn] "); btPrint(turnsCompleted); btPrint("/"); btPrintln(Max_Turns);
  }

  if (turnsCompleted >= Max_Turns && finalStopAtMs == 0) {
    if (lastTurnAtMs == 0) lastTurnAtMs = millis();
    float settleErr = fabsf(wrapAngle180(getCurrentHeading() - headingTarget));   // extra IMU read, this phase only
    if (settleErr < RA || millis() - lastTurnAtMs > Calibrate_Max) {
      finalStopAtMs = millis() + Stop_Condition;                        // last turn done -> timed run-on starts NOW
      btPrintln("[turn] last turn settled - final run-on");
    }
  }
  if (finalStopAtMs != 0 && millis() >= finalStopAtMs) { // steering stayed live through the run-on
  motorBrake();
  digitalWrite(2, HIGH);   // blue LED on — all rounds complete
  btPrintln("Run complete - motor braked.");
  while (1) delay(100);
  }
}

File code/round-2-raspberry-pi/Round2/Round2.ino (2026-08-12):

#include <Wire.h>
#include <math.h>
#include <Adafruit_Sensor.h>
#include "BluetoothSerial.h"
#include <Adafruit_BNO055.h>
#include <ESP32Servo.h>

// ---- WiFi tuning console ----
#include <WiFi.h>
#include <WebServer.h>
#include <Preferences.h>
#include <ESPmDNS.h>


// ==========================================
//           PIN & HARDWARE DEFINITIONS
// ==========================================
#define SERVO_PIN 13


// Left Motor Pins
#define MOTOR_IN1  25
#define MOTOR_IN2  26
#define MOTOR_PWM  33


// I2C Multiplexer Channels (HW-617)
#define MUX_CH_LEFT   0
#define MUX_CH_CENTER 1
#define MUX_CH_RIGHT  2
#define MUX_CH_BNO    4


#define TFLUNA_I2C_ADDR 0x10


// ==========================================
//          CONFIGURABLE VARIABLES
// ==========================================
int STRAIGHT_SPEED = 80;  // Cruise speed for driving straight (0-255)
int TURN_SPEED     = 80;  // Kept for tuner/Bluetooth compatibility
int BACKWARD_SPEED = -80; // Speed used during the reversing arc

const int RAMP_START_SPEED = 30;
const int RAMP_STEP = 30;
const unsigned long RAMP_DURATION_MS = 2000;


int SERVO_CENTER   = 117;   // Dead-center steering alignment
int DIFF = 25;
int SERVO_MAX_LEFT = SERVO_CENTER + DIFF;  // Physical mechanical limit for left turn
int SERVO_MAX_RIGHT= SERVO_CENTER - DIFF;  // Physical mechanical limit for right turn

// Change to true if your steering corrections move backwards during testing
const bool INVERT_STEERING = true;

float STEERING_KP  = 1.2;
float STEERING_KI  = 0.02;
float STEERING_KD  = 0.15;
const float HEADING_DEADBAND = 1.5;   // degrees — ignore jitter smaller than this
const int   MAX_STEER_CORRECTION = 20; // clamp — no single correction can swing the servo too hard
const int MAX_TURNS      = 12;   // Total number of turns allowed before tracking the final stop distance

unsigned long turnCooldownUntil = 0;   // timestamp until which obstacle checks are ignored
// ---- Obstacle avoidance (serial commands from the Pi) ----
bool avoidDirectionRight = true;               // true = swerve right, false = swerve left
unsigned long lastObstacleCmd = 0;             // timestamp of last RED/GREEN command
const unsigned long OBSTACLE_TIMEOUT_MS = 5000; // auto-clear after 5s of no command
const unsigned long TURN_COOLDOWN_MS = 1000; // how long to ignore front-wall checks after a turn

// Cardinal heading snap table — every commanded turn target is forced onto one of these,
// so sensor noise/drift can never leave the robot aiming at something like 250°.
const float CARDINAL_HEADINGS[4] = {0.0, 90.0, 180.0, 270.0};

// ==========================================
//      FRONT-DISTANCE TURN TRIGGER
// ==========================================
// Start a reversing-arc turn once the front (center) LiDAR stays this close.
int FRONT_TURN_DISTANCE = 10;              // cm — start the turn maneuver once front gets this close
bool frontConditionActive = false;         // true while front has been continuously "close"
unsigned long frontConditionStartTime = 0; // millis() timestamp when it first became true
const unsigned long FRONT_CONFIRM_MS = 150; // debounce so one noisy reading doesn't trigger a turn

// ==========================================
//           REVERSING ARC TURN
// ==========================================
// Instead of a three-point turn, a wall trigger backs the robot up with the
// servo cranked by ARC_SERVO_ANGLE. The IMU is watched until heading is
// within ARC_EXIT_THRESHOLD of the target cardinal, then wheels center and
// straight driving resumes.
//
// Tune these for lane width and how square the exit needs to be:
int ARC_SERVO_ANGLE = 20;              // degrees off center — how sharp the reverse arc is
float ARC_EXIT_THRESHOLD = 8.0;        // degrees — how precisely it must face the target before exiting
unsigned long ARC_PAUSE_MS = 500;      // stand still after the 50 cm / 150 ms confirm, before reversing
unsigned long ARC_MIN_MS = 400;        // prevent an instant exit if heading is already close
unsigned long ARC_MAX_MS = 4000;       // safety timeout — force-exit the arc even if still off heading

enum TurnPhase { PHASE_PAUSE, PHASE_REVERSE };
TurnPhase currentTurnPhase = PHASE_PAUSE;
unsigned long turnPhaseStartTime = 0;
unsigned long arcStartTime = 0;

// ==========================================
//     PI WAYPOINT (STOP / WAYPOINT / REVERSE)
// ==========================================
// Pi sends STOP then WAYPOINT,color,xa,ya,xc,yc,R,theta,arclen
float WHEELBASE_CM = 9.0;                 // used to turn radius into a servo angle
unsigned long WAYPOINT_PAUSE_MS = 400;     // stand still after STOP before driving to C
float WAYPOINT_EXIT_DEG = 8.0;             // IMU heading error that counts as "arrived"
unsigned long WAYPOINT_MIN_MS = 250;
unsigned long WAYPOINT_MAX_MS = 4000;
float ESTIMATED_FWD_CMS = 30.0;            // rough cm/s at STRAIGHT_SPEED — backup timer

bool waypointReady = false;
float waypointStartHeading = 0.0;
float waypointTargetHeading = 0.0;
float waypointRadiusCm = 0.0;
float waypointThetaDeg = 0.0;
float waypointArcLenCm = 0.0;
int waypointServoAngle = 90;
unsigned long piHoldStart = 0;
unsigned long waypointArcStart = 0;
unsigned long lastPiCmd = 0;

// ==========================================
//           PARALLEL PARKING (Magenta)
// ==========================================
// Pi sends a single "PARK\n" line once it sees the magenta marker close
// enough. From there the ESP32 runs the entire maneuver itself:
//   1) PARK_APPROACH  — keep driving straight briefly to clear the slot
//   2) PARK_PAUSE1     — stop
//   3) PARK_REVERSE_IN — reverse with steering cranked toward the slot,
//                        rotating the robot into the lot at an angle
//   4) PARK_PAUSE2     — stop
//   5) PARK_STRAIGHTEN — reverse with opposite steering, straightening
//                        back to the original heading (parallel to wall)
//   6) PARK_FINISH     — stop, mark run complete
//
// Direction (left/right slot) is auto-detected from whichever side LiDAR
// reports more room at the moment PARK is received. If that guesses wrong
// on your track, flip the ">" to "<" in handlePiPark() below.
//
// NOTE: the exact steering direction in parkCrankServoAngle() is a starting
// guess. If PARK_REVERSE_IN backs the robot AWAY from the slot instead of
// into it, swap the two parkCrankServoAngle(...) calls in executeParking().
enum ParkPhase { PARK_APPROACH, PARK_PAUSE1, PARK_REVERSE_IN, PARK_PAUSE2, PARK_STRAIGHTEN, PARK_FINISH };
ParkPhase currentParkPhase = PARK_APPROACH;
unsigned long parkPhaseStartTime = 0;
bool parkDirectionRight = true;     // true = slot is on the robot's right, false = left
float parkStartHeading = 0.0;
float parkTargetHeading1 = 0.0;     // heading target while backing into the slot at an angle
float parkTargetHeading2 = 0.0;     // final heading — parallel to the wall (== parkStartHeading)
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

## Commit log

2026-06-26 Initial commit: scaffold WRO Future Engineers 2026 repository
    - Add placeholder sensor driver files for IR line sensors, ultrasonic/TOF, and IMU
    - Add initial testing scripts used to bring up hardware for the first time
    - No control logic yet; this is bring-up/bootstrap only
2026-06-26 refactor: restructure repo around round-1-esp32 / round-2-raspberry-pi / shared
    - Split all code into three top-level folders matching the two competition rounds plus shared utilities
    - Add hardware specification table covering power draw, communication protocol, top speed, and degrees of freedom per component
    - Document TCA9548A I2C multiplexer wiring used to run TF-Luna distance sensor and BNO055 IMU on the same bus without address conflicts
    - Rename project and update README to reflect new architecture
2026-06-26 chore: add .gitkeep placeholders to preserve empty directory structure
    - Git does not track empty folders, so add .gitkeep files to each intended-but-currently-empty directory
    - Ensures a fresh clone gives teammates the full folder skeleton without manual recreation
2026-06-27 perf(camera): optimize capture pipeline for higher frame rate
    - Reduce per-frame processing overhead in the camera read loop
    - Cut latency between frame capture and downstream detection logic
    - Result: noticeably smoother real-time obstacle detection at higher FPS
2026-07-04 docs: clean up code comments and add hardware setup notes
    - Remove outdated/misleading inline comments across control code
    - Add setup notes covering wiring order, power-on sequence, and known gotchas for new team members
2026-07-04 docs(readme): document ESP32 and Raspberry Pi 5 GPIO pinouts
    - Add full pin mapping table for ESP32 (round 1) and Raspberry Pi 5 (round 2)
    - Intended as the single source of truth for wiring, replacing tribal knowledge
2026-07-08 refactor: separate camera/detection code from model-training code
    - Move real-time inference code (used on the robot) into its own folder
    - Move offline model-training scripts (used on dev machines, not the robot) into a separate folder
    - Goal: avoid shipping training-only dependencies to the robot's runtime environment
    [Motor_Test_Code.ino, Round1.ino, capture.py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]
2026-07-10 fix: correct typo in neural-network folder name
    - Rename misspelled folder to match naming convention used elsewhere in repo
    - No code logic changes, path reference only
    [capture.py, prepare.py]
2026-07-10 fix(hardware): resolve GPIO pin conflicts on microcontroller
    - Identify and reassign pins that were double-mapped between a sensor and the motor driver
    - Root cause of intermittent motor stalling observed during bench testing
    [capture.py, prepare.py]
2026-07-18 fix(line-tracking): tune IR sensor threshold values
    - Adjust black/white detection thresholds based on latest bench calibration under competition lighting
    - Improves line-tracking accuracy near track edges and reduces false line-loss triggers
    [Round1.ino]
2026-07-22 fix(controller): resolve timing/delay bug in main control loop
    - Fix a delay miscalculation that was causing the loop to occasionally skip sensor reads
    - Improves control loop consistency, particularly during rapid direction changes
    [Round1.ino, Servo_Test.ino]
2026-07-26 feat(telemetry): add WiFi-based live monitoring; update round-1 code
    - Add WiFi telemetry so sensor values and control state can be observed live during testing without a wired connection
    - Update round-1 ESP32 control code to log telemetry alongside existing serial debug output
2026-08-05 refactor(sensors): rewrite sensor feedback loop for stability
    - Replace previous feedback loop implementation to reduce noise-driven steering jitter
    - Smooths out erratic corrections previously caused by raw, unfiltered sensor readings
2026-08-05 chore: add required external libraries and reference files
    - Vendor/add third-party libraries needed to build the current codebase
    - Add reference documentation used during development (datasheets, example code)
2026-08-07 tune(round1): adjust steering sensitivity and speed values
    - Recalibrate steering sensitivity coefficient and base/max speed constants
    - Based on Round 1 bench and track test results, aiming for smoother cornering without overcorrection
2026-08-08 feat(round2): begin open-challenge (obstacle avoidance) development
    - Start initial obstacle-avoidance logic scaffold for Round 2
    - Not yet integrated with full sensor suite; early-stage groundwork only
    [Round2.ino, pycam_round2.py]
2026-08-08 docs(calibration): add vehicle sensor calibration logs
    - Record calibration data for IMU (BNO055) and distance sensor (TF-Luna)
    - Serves as reference baseline for future recalibration or drift diagnosis
    [pycam_round2.py]
2026-08-09 feat(round2): update obstacle-avoidance code for testing
    - Refine obstacle-avoidance algorithm ahead of Round 2 track testing
    - Incorporates adjustments from earlier bench observations
    [pycam_round2.py]
2026-08-09 fix(round2): fix pathing bugs, update main control logic
    - Fix bugs in path-planning logic that caused incorrect trajectory decisions around obstacles
    - Update main control loop to reflect corrected pathing behavior
    [pycam_round2.py]
2026-08-10 refactor(round1): revert WiFi-tuner/PID build to simpler Bluetooth-tuned P control
    - Remove WiFi SoftAP tuning webpage, flash-persisted tunables, PID
    (integral+derivative) steering, heading smoothing filter, speed
    ramp-up, and distance-based stop condition
    - Keep turn-lock logic, turn cooldown, TF-Luna mux reads, Bluetooth
    NAME=VALUE tuning console, BNO055 heading capture
    - Reason: WiFi tuner + PID stack added complexity/failure points
    without clear benefit on the track; simpler loop is easier to
    tune live and reason about
    - Renamed #define constants to tunable variables for BT console access
    [Lenovo 300 FHD webcam mount.stl, Lenovo Webcom 300 Camera Bracket Front.stl, Lenovo Webcom 300 Camera Bracket Rear.stl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]
2026-08-12 chore: finalize changes for August 12 submission
    - Final review pass before competition submission deadline
    - Verify build correctness, clean up stray files, confirm docs match current code state
    [Round1.ino, Round2.ino, capture.py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]
